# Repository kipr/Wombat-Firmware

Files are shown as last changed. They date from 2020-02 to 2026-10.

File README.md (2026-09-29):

Wombat Firmware
=======
> To view the history of this project, go to https://github.com/kipr/Wallaby-Firmware. This is a direct copy of the Wallaby2-V8 branch of that repository.

# General

This project provides firmware for the STM32F427VIT6 Microcontroller on the Wombat.

It is currently under active development by KIPR.

# Structure

* build
    * This folder contains the output wombat.bin file, which can be flashed onto the microcontroller.
* CMake
    * Toolchain file, to compile the firmare using arm-gcc
* docs
    * Datasheets, Schematics and Bill of Materials for the Wombat Controller
* Firwmare
    * Actual firmware reading the sensors, controlling the motors, ...
* libs
    * STM32 Standard Peripheral Library used to interact with the different periphials of the microcrontroller
* linker
    * STM32F4 linker script

## Run/Build with Docker

> docker compose build

> docker compose run --rm build-wombat-firmware

This builds the firmware and writes wombat.bin to build/Firmware/. Use `run` rather than `up`: `up` reports success even when the build fails.

## Run/Build Directly

(Requires PATH to be setup correctly for gcc/G++)

> sudo build.sh

### Author(s): 
 
Joshua Southerland (2015)

Zachary Sasser (2019)

#### Contributors:
 
Konstantin Lampalzer, [HTL Wiener Neustadt](https://robo4you.at/) (2020) - Added the open-source CMake build and Docker support

Want to Contribute? Start Here!:
https://github.com/kipr/KIPR-Development-Toolkit

Then read [CONTRIBUTING.md](CONTRIBUTING.md) for how we work, including with AI coding agents.

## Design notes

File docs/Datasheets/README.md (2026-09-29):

# Datasheets

Each file is named by the component's reference designator on the Wombat
schematic (`../Schematics/`). Part numbers come from the bill of materials
(`../Wombat_BOM_rev4.xlsx`) and the schematic.

| File | Part | Role |
|---|---|---|
| `U37.pdf` | STMicroelectronics STM32F427VIT6 | Microcontroller this firmware runs on |
| `U5.pdf` | InvenSense MPU-9250 | 9-axis IMU (accelerometer, gyroscope, magnetometer), on SPI3 |
| `U61.pdf`, `U64.pdf` | Toshiba TB6612FNG | Dual H-bridge motor drivers |
| `U38.pdf` | Epson TSX-3225, 24.000 MHz | Main crystal; matches `HSE_VALUE` in `CMakeLists.txt` |
| `U44.pdf` | ECS ECS-.327-12.5-34B, 32.768 kHz | Low-speed crystal |
| `U43.pdf` | Maxim DS1340U-33 | Real-time clock |
| `U2.pdf` | Microchip 24LC02B | 2 Kbit I²C EEPROM |
| `U67.pdf` | Microchip AT24CS01 | 1 Kbit I²C EEPROM with serial number |
| `U56.pdf` | TI TXS0104E | 4-bit bidirectional voltage-level translator |
| `U1.pdf` | TI TFP401 | DVI/HDMI receiver |
| `X1.pdf` | Molex 47151-0001 | HDMI connector |
| `U7.pdf` | TI LM3671MF-3.3 | 3.3 V step-down regulator |
| `U72.pdf`, `U73.pdf` | Diodes Inc. AP65502 | Step-down regulators |
| `U4.pdf` | Fairchild FAN5333B | Voltage regulator |
| `U8.pdf` | Sumida CDRH2D14NP-2R2NC | 2.2 µH inductor |
| `Q1.pdf`, `Q2.pdf` | P-channel MOSFETs | The BOM lists ON Semi NTF6P02T3G; the datasheet files are for Infineon BSP170P |
| `U45 (DNP).pdf` | Maxim MAX98357 | I²S audio amplifier; not populated (DNP) |

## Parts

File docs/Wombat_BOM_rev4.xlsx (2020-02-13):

Item # | Qty | Ref Des | Manufacturer | Mfg Part # | Dist Part # | Distributor | Description | Package | Type | Replacement | Remakrs
66 | 66 | 66 | 66 | 66 | 65 | 66 | 65 | 66 | 66
1 | 1 | J3 | Harwin | M20-7821042 | 855-M20-7821042 | mouser | 1x10 female header | J3 | Thru-hole | 2-1001FBV0T | Chinese Brand
2 | 1 | J1 | Harwin | M20-7831046 | 855-M20-7831046 | mouser | 2x10 female header | 2X10 | Thru-hole | 2-2002FBV0T | Chinese Brand
3 | 1 | J7 | Harwin | M20-7820642 | 855-M20-7820642 | mouser | 1x6 female header | 1X06 | Thru-hole | 2-0601FBV0T | Chinese Brand
4 | 1 | U35 | C&K | 0S102011MA1QN1 | 611-OS102011MA1QN1 | mouser |  | OS-SPDT-MINI-SLIDE_SWITCH | Thru-hole
5 | 4 | R48,R66,R72, R73 | Yageo | RC0603JR-070RL | 603-RC0603JR-070RL | mouser | 0 ohm 0603 | 0603 | smt
6 | 32 | C2, C3,C4,C5,C6,C7,C8, C9, C10, C11,C19,C22, C26, C27, C28, C31, C32, C34, C40, C41, C42, C43, C44, C45, C46, C48, C51, C54, C60, C67, C69, C70 | Taiyo Yuden | TMK107BJ104KA-T | 963-TMK107BJ104KA-T | mouser | 0.1uF 25V | 0603-CAP | smt
7 | 4 | R38, R52, R56,R64 | Yageo | RC0603FR-10100KL | 603-RC0603FR-10100KL | mouser | 100k 1% | 0603-RES | smt
8 | 11 | R1, R2, R5, R8,R11, R32, R45, R50, R54, R58, R65 | Yageo | RC0603FR-0710KL | 603-RC0603FR-0710KL | mouser | 10k 1% | 0603-RES | smt
9 | 2 | R49, R53 | Yageo | RC0603FR-0710K5L | 603-RC0603FR-0710K5L | mouser | 10k5 1% | 0603-RES | smt
10 | 2 | C61, C68 | Yageo | CC0603KRX7R8BB103 | 603-CC603KRX7R8BB103 | mouser | 10nF 25V | 0603-CAP | smt
11 | 1 | C71 | KEMET | C0603C100J5GACTU | 80-C0603C100J5G | mouser | 10pF 50v | 0603 | smt
12 | 1 | C16 | Murata | GRM21BR61E106KA73L | 81-GRM21BR61E106KA3L | mouser | 10uF 20V 20% | 0805-NO | smt
13 | 5 | C1,C29, C30, C49, C50 | Murata | GRM188R61E106MA73J | 81-GRM188R61E106MA3J | mouser | 10uF 20V | 0603-CAP | smt
14 | 2 | R15, R16 | Yageo | RC0805FR-0712RL | 603-RC0805FR-0712RL | mouser | 12 ohm 1% 0805 | 0805-NO | smt
15 | 1 | L1 | Taiyo Yuden | NRS5040T150MMGJV | 963-NRS5040T150MMGJV | mouser | 15uH | INDUCTOR_5X5MM_NR5040_NOTHERMALS | smt
16 | 8 | R9, R10, R12, R13, R28, R30, R31, R57 | Yageo | RC0603FR-071KL | 603-RC0603FR-071KL | mouser | 1K ohm 1% | 0603-RES | smt
17 | 1 | D3 | Fairchild | 1N4148WS | 512-1N4148WS | mouser | 1N4148 | SOD-323 | smt
18 | 2 | C33, C36 | Taiyo Yuden | TMK107B7105KA-T | 587-2984-1-ND | digikey | 1uF | 0603-CAP | smt
19 | 2 | C17, C18 | Yageo | CC0805KKX7R9BB105 | 603-CC805KKX7R9BB105 | mouser | 1uF 50V 10% | 0805-NO | smt
20 | 3 | C37, C38,C12 | Murata | GRM188R61E225KA12D | 81-GRM188R61E225KA2D | mouser | 2.2uF | 0603-CAP | smt
21 | 1 | U8 | Sumida | CDRH2D14NP-2R2NC | 851-CDRH2D14NP-2R2NC | mouser | 2.2uH | 3P2MM-X-3P2MM-INDUCTOR | smt
22 | 6 | C20, C21, C35, C47, C52, C53 | KEMET | C0603C220J5GACTU | 80-C0603C220J5G | mouser | 22pF | 0603 | smt
23 | 6 | C55, C56, C57, C62, C63, C64 | AVX | 1210YD226KAT2A | 581-1210YD226K | mouser | 22uF 16V | 1210@1 | smt | CL32A226KOJNNNE | 22uF(226) ±10% 16V 1210
24 | 1 | R29 | Yageo | RC0603FR-07240RL | 603-RC0603FR-07240RL | mouser | 240R | 0603-RES | smt
25 | 1 | U74 | Littelfuse Inc. | 2920L500/16MR | 576-2920L500/16MR | mouser | 2920L500-16MR 16V 5A Poly Fuse | FUSE-2920 | smt
26 | 1 | J15 | Harwin | M20-7830646 | 855-M20-7830646 | mouser | 2X6 FEMALE | 2X6 | Thru-hole | 2-1202FBV0T | Chinese Brand
27 | 8 | R20, R21, R24, R25, R39, R40, R43, R44 | Yageo | RC0603FR-072K2L | 603-RC0603FR-072K2L | mouser | 2k2 1% | 0603-RES | smt
28 | 1 | C25 | Panasonic | EEE-FTC331XAP | 667-EEE-FTC331XAP | mouser | 330uF 16V Electrolytic Cap | PANASONIC_D | smt
29 | 1 | R37 | Yageo | RC0603FR-073K3L | 603-RC0603FR-073K3L | mouser | 3K3 1% | 0603-RES | smt
30 | 2 | C24, C39 | Murata | GRM188R61E475KE11D | 81-GRM188R61E475KE1D | mouser | 4.7uF | 0603-CAP | smt
31 | 1 | J9 | TE Connectivity | 4-1734839-0 | 571-4-1734839-0 | mouser | Touchscreen Connector 40 Pin | 4-1734839-0 | smt
32 | 8 | R14, R17, R18, R19, R33, R34, R35, R36 | Yageo | RC0603FR-07470RL | 603-RC0603FR-07470RL | mouser | 470R 1% | 0603-RES | smt
33 | 1 | X1 | Molex | 47151-0001 | 538-47151-0001 | mouser | 47151-0001 | HDMI_MOLEX_47151-0001_DIMLAYER | smt, thru-hole posts
34 | 1 | R7 | Yageo | RC0603FR-0747KL | 603-RC0603FR-0747KL | mouser | 47k 1% | 0603 | smt
35 | 2 | C58, C65 | Murata | GRM32EC81C476KE15L | 81-GRM32EC81C476KE5L | mouser | 47uF 10%ToL | 1210@1 | smt
36 | 1 | R55 | Yageo | RC0603FR-0752K3L | 603-RC0603FR-0752K3L | mouser | 52k3 1% | 0603-RES | smt
37 | 2 | L2,L4 | Vishay | IHLP3232CZER6R8M01 | 70-IHLP3232CZER6R8M0 | mouser | 6.5uH | INDUCT-3232-1050 | smt
38 | 1 | R51 | Yageo | RC0603FR-0764K9L | 603-RC0603FR-0764K9L | mouser | 64k9 1% | 0603-RES | smt
39 | 8 | R22, R23, R26, R27, R41, R42, R46, R47 | Yageo | RC0603FR-076K8L | 603-RC0603FR-076K8L | mouser | 6k8 1% | 0603-RES | smt
40 | 2 | C59, C66 | Yageo | CC0603JRX7R9BB682 | 603-CC603JRX7R9BB682 | mouser | 6p8nF | 0603-CAP | smt
41 | 1 | U5 | InvenSense | MPU-9250 | 1428-1019-1-ND | digikey | 9DoF IMU | QFN24-3X3 | smt
42 | 1 | U$8 | Texas Instruments | TSC2007IPWR | 595-TSC2007IPWR | mouser | TSC2007 | TSSOP16 | smt
43 | 2 | U72, U73 | Diodes Incorporated | AP65502SP-13 | 621-AP65502SP-13 | mouser | DC/DC Buck | SOT-23-Thin-6 | smt
44 | 4 | U62, U63, U65, U66 | Kingbright | APB3025ESGC-F01 | 604-APB3025ESGC-F01 | mouser | APB3025ESGC-F01 | DUAL_SMT_LED | smt
45 | 1 | U67 | Microchip | AT24CS01-STUM-T | 556-AT24CS01-STUM-T | mouser | AT24CS01-STUM-T | SOT-23-5 | smt
46 | 2 | Q1, Q2 | ON Semiconductor | NTF6P02T3G | 863-NTF6P02T3G | mouser | P-CH 20V FET | SOT223 | smt
47 | 1 | U42 | Keystone | 2998TR | 534-2998TR | mouser | COINCELL_6P8MM | COIN_CELL_HOLDER_6P8MM | smt
48 | 4 | U30, U41, U76, U77 | TE Connectivity | 5-103414-1 | 571-5-103414-1 | mouser | CONN-HEADER-5-103414-1 | HEADER-5-103414-1 | Thru-hole
49 | 1 | J2 | Adafruit | 1992 |  | adafruit | 2x20 tall female Pi connector | 2X20 | Thru-hole | Still sourcing for lower price
50 | 1 | U44 | ECS | ECS-.327-12.5-34B-TR | 520-327-12.5-34B | mouser | CRYSTAL-ECS-ECX34B 32.768KHz | CRYSTAL-ECX34B-3P2MM_1P5MM | smt
51 | 1 | U43 | Maxim Integrated | DS1340U-33+ | 700-DS1340U-33 | mouser | DS1340U | USOP-8 | smt | DS1340U-33+T&R | Detailed part number is DS1340U-33+T&R
52 | 1 | U4 | Fairchild | FAN5333BSX | 512-FAN5333BSX | mouser | FAN5333BSX | SOT23-5 | smt
53 | 2 | J8, J10 | Harwin | M20-7830342 | 855-M20-7830342 | mouser | FEMALE 2x3 | 2X3 | Thru-hole | 2-0602FBV0T | Chinese Brand
54 | 4 | U68, U69, U70, U71 | Littelfuse Inc. | 0603L175SLYR | 576-0603L175SLYR | mouser | FUSE-RESET-0603L100SLYR | 0603 | smt
55 | 4 | FB1, FB2, FB3, FB4 | Murata | BLM21AG601SN1D | 81-BLM21A601F | mouser | Ferrite | _0805MP | smt
56 | 1 | U7 | Texas Instruments | LM3671MF-3.3/NOPB | 926-LM3671MF-3.3NOPB | mouser | LM3671 | SOT-23-5 | smt
57 | 1 | D1 | Fairchild | MBR0540 | 512-MBR0540 | mouser | MBR0540 | SOD-123 | smt
58 | 1 | D2 | OM Semiconductor | 1SMB5934BT3G | 863-1SMB5934BT3G | mouser | 24V 3W Zener | SMADIODE | smt
59 | 1 | U75 | TE Connectivity | 1571527-2 | 506-1571527-2 | mouser | PUSHBUTTON-1571527-2 | BUTTON-1571527-2 | smt
60 | 1 | U37 | STMicroelectronics | STM32F427VIT6 | 511-STM32F427VIT6 | mouser | STM32F427VIT6 | LQFP-100 | smt
61 | 2 | U61, U64 | Toshiba | TB6612FNG,C,8,EL | 757-TB6612FNGC8EL | mouser | TB6612FNG | SSOP24 | smt
62 | 1 | U1 | Texas Instruments | TFP401AIPZPRQ1 | 595-TFP401AIPZPRQ1 | mouser | TFP401 | S-PQFP-G100 | smt
63 | 1 | U38 | Epson Timing | TSX-3225 24.0000MF20G-AC3 | 732-TX325-24F20G-AC3 | mouser | TSX-3325 24.000MHz Crystal | TSX-3225 | smt
64 | 1 | U56 | Texas Instruments | TXS0104EPWR | 595-TXS0104EPWR | mouser | TXS0104 | TSSOP14 | smt
65 | 1 | D4 | Lite-On | LTST-C190KRKT | 859-LTST-C190KRKT | mouser | Red 0603 led | LED-0603 | smt
66 | 1 | D5 | Lite-On | LTST-C190KSKT | 859-LTST-C190KSKT | mouser | Yellow 0603 led | LED-0603 | smt

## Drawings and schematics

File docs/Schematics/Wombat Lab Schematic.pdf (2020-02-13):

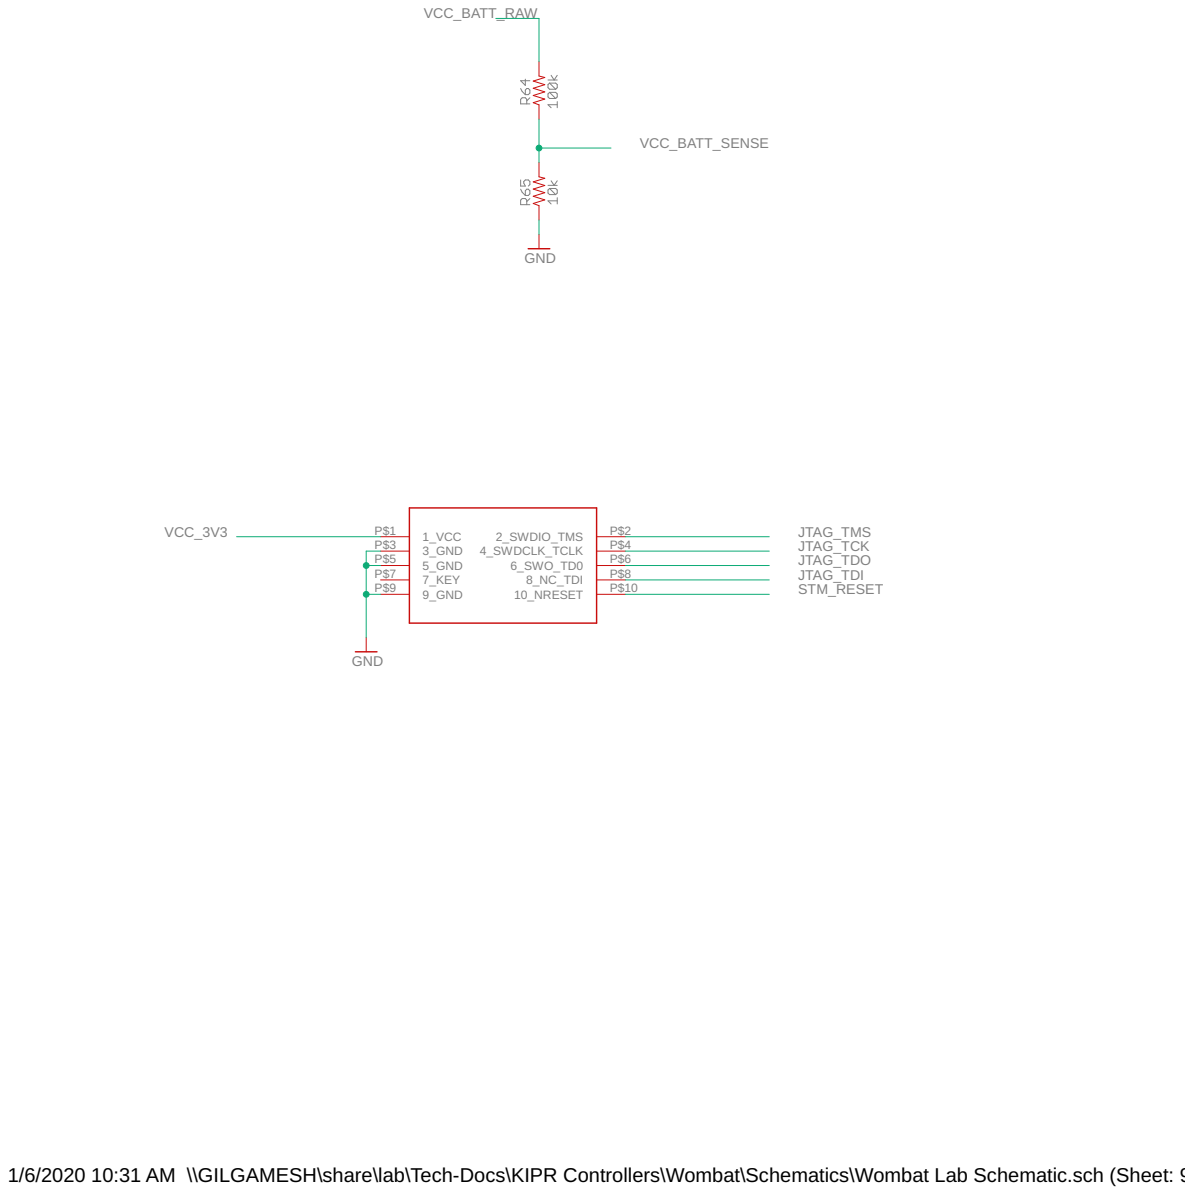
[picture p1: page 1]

1/6/2020 10:31 AM \\GILGAMESH\share\lab\Tech-Docs\KIPR Controllers\Wombat\Schematics\Wombat Lab Schematic.sch (Sheet: 9/17)

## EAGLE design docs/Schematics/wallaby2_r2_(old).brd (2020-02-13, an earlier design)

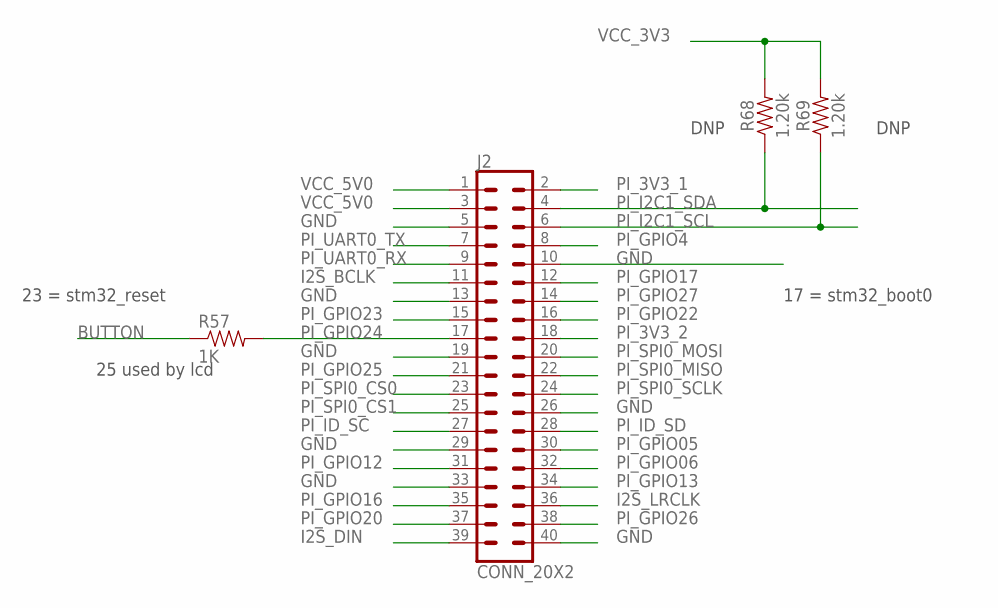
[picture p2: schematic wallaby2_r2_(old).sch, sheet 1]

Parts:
J2: CONN_20X2; 2X20
R57: 1K; 0603-RES
R68, R69: 1.20k; 0603

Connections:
BUTTON: R57.1; also elsewhere on the board
GND: J2.5, J2.10, J2.13, J2.19, J2.26, J2.29, J2.33, J2.40; also elsewhere on the board
I2S_BCLK: J2.11; also elsewhere on the board
I2S_DIN: J2.39; also elsewhere on the board
I2S_LRCLK: J2.36; also elsewhere on the board
PI_3V3_1: J2.2
PI_3V3_2: J2.18
PI_GPIO4: J2.8
PI_GPIO05: J2.30
PI_GPIO06: J2.32
PI_GPIO12: J2.31
PI_GPIO13: J2.34
PI_GPIO16: J2.35
PI_GPIO17: J2.12; also elsewhere on the board
PI_GPIO20: J2.37
PI_GPIO22: J2.16
PI_GPIO23: J2.15; also elsewhere on the board
PI_GPIO24: J2.17, R57.2
PI_GPIO25: J2.21; also elsewhere on the board
PI_GPIO26: J2.38
PI_GPIO27: J2.14
PI_I2C1_SCL: J2.6, R69.1; also elsewhere on the board
PI_I2C1_SDA: J2.4, R68.1; also elsewhere on the board
PI_ID_SC: J2.27
PI_ID_SD: J2.28
PI_SPI0_CS0: J2.23; also elsewhere on the board
PI_SPI0_CS1: J2.25
PI_SPI0_MISO: J2.22; also elsewhere on the board
PI_SPI0_MOSI: J2.20; also elsewhere on the board
PI_SPI0_SCLK: J2.24; also elsewhere on the board
PI_UART0_RX: J2.9; also elsewhere on the board
PI_UART0_TX: J2.7; also elsewhere on the board
VCC_3V3: R68.2, R69.2; also elsewhere on the board
VCC_5V0: J2.1, J2.3; also elsewhere on the board

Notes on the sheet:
25 used by lcd
23 = stm32_reset
17 = stm32_boot0
DNP

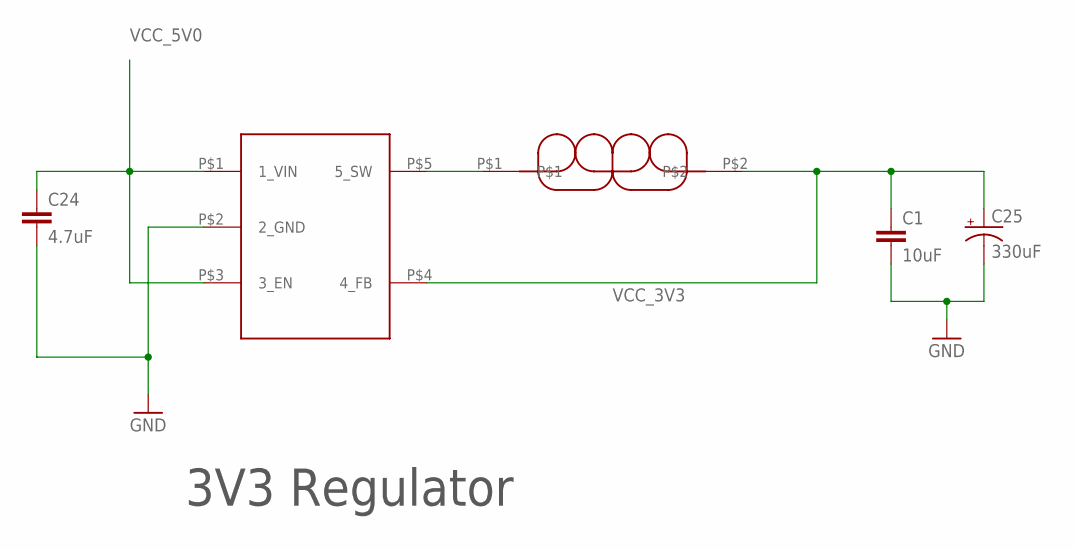
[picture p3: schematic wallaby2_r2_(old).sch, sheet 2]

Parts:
C1: 10uF; 0603-CAP
C24: 4.7uF; 0603-CAP
C25: 330uF; PANASONIC_D
U7: LM3671; SOT-23-5
U8: 2.2uH; 3P2MM-X-3P2MM-INDUCTOR

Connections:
GND: C1.2, C24.2, C25.-, U7.P$2 (2_GND); also elsewhere on the board
unnamed: U7.P$5 (5_SW), U8.P$1
VCC_3V3: C1.1, C25.+, U7.P$4 (4_FB), U8.P$2; also elsewhere on the board
VCC_5V0: C24.1, U7.P$1 (1_VIN), U7.P$3 (3_EN); also elsewhere on the board

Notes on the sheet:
3V3 Regulator

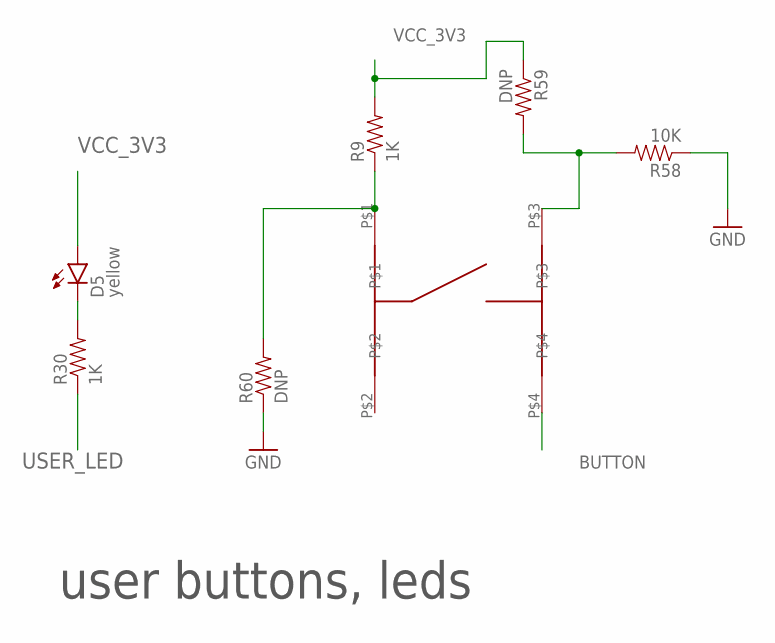
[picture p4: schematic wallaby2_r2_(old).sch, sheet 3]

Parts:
D5: yellow; LED-0603
R9, R30: 1K; 0603-RES
R58: 10K; 0603-RES
R59, R60: DNP; 0603-RES
U75: PUSHBUTTON-1571527-2; BUTTON-1571527-2

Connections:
BUTTON: U75.P$4; also elsewhere on the board
GND: R58.1, R60.1; also elsewhere on the board
unnamed: D5.C, R30.2
unnamed: R9.1, R60.2, U75.P$1
unnamed: R58.2, R59.2, U75.P$3
USER_LED: R30.1; also elsewhere on the board
VCC_3V3: D5.A, R9.2, R59.1; also elsewhere on the board

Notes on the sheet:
user buttons, leds

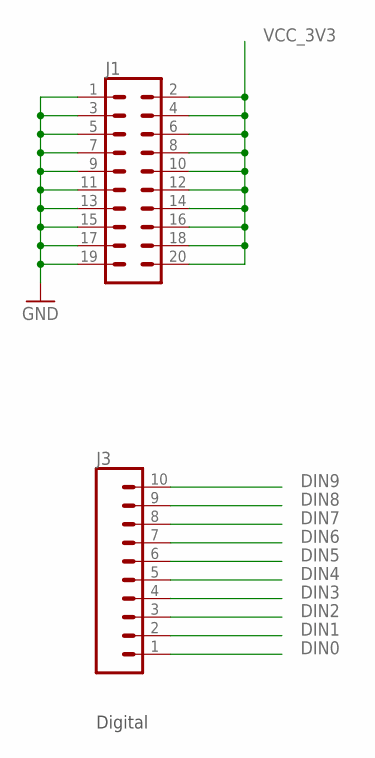
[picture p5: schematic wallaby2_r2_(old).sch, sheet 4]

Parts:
J1: CONN_10X2; 2X10
J3: CONN_10"; 1X10

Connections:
DIN0: J3.1; also elsewhere on the board
DIN1: J3.2; also elsewhere on the board
DIN2: J3.3; also elsewhere on the board
DIN3: J3.4; also elsewhere on the board
DIN4: J3.5; also elsewhere on the board
DIN5: J3.6; also elsewhere on the board
DIN6: J3.7; also elsewhere on the board
DIN7: J3.8; also elsewhere on the board
DIN8: J3.9; also elsewhere on the board
DIN9: J3.10; also elsewhere on the board
GND: J1.1, J1.3, J1.5, J1.7, J1.9, J1.11, J1.13, J1.15, J1.17, J1.19; also elsewhere on the board
VCC_3V3: J1.2, J1.4, J1.6, J1.8, J1.10, J1.12, J1.14, J1.16, J1.18, J1.20; also elsewhere on the board

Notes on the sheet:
Digital

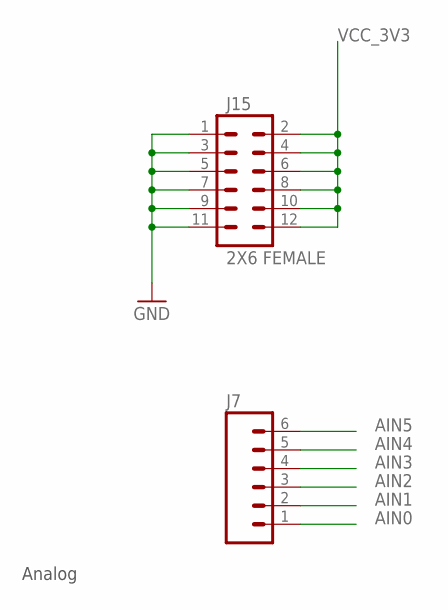
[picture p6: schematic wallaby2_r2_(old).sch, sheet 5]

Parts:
J7: M06SILK_FEMALE_PTH; 1X06
J15: 2X6 FEMALE; 2X6

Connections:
AIN0: J7.1; also elsewhere on the board
AIN1: J7.2; also elsewhere on the board
AIN2: J7.3; also elsewhere on the board
AIN3: J7.4; also elsewhere on the board
AIN4: J7.5; also elsewhere on the board
AIN5: J7.6; also elsewhere on the board
GND: J15.1, J15.3, J15.5, J15.7, J15.9, J15.11; also elsewhere on the board
VCC_3V3: J15.2, J15.4, J15.6, J15.8, J15.10, J15.12; also elsewhere on the board

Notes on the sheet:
Analog

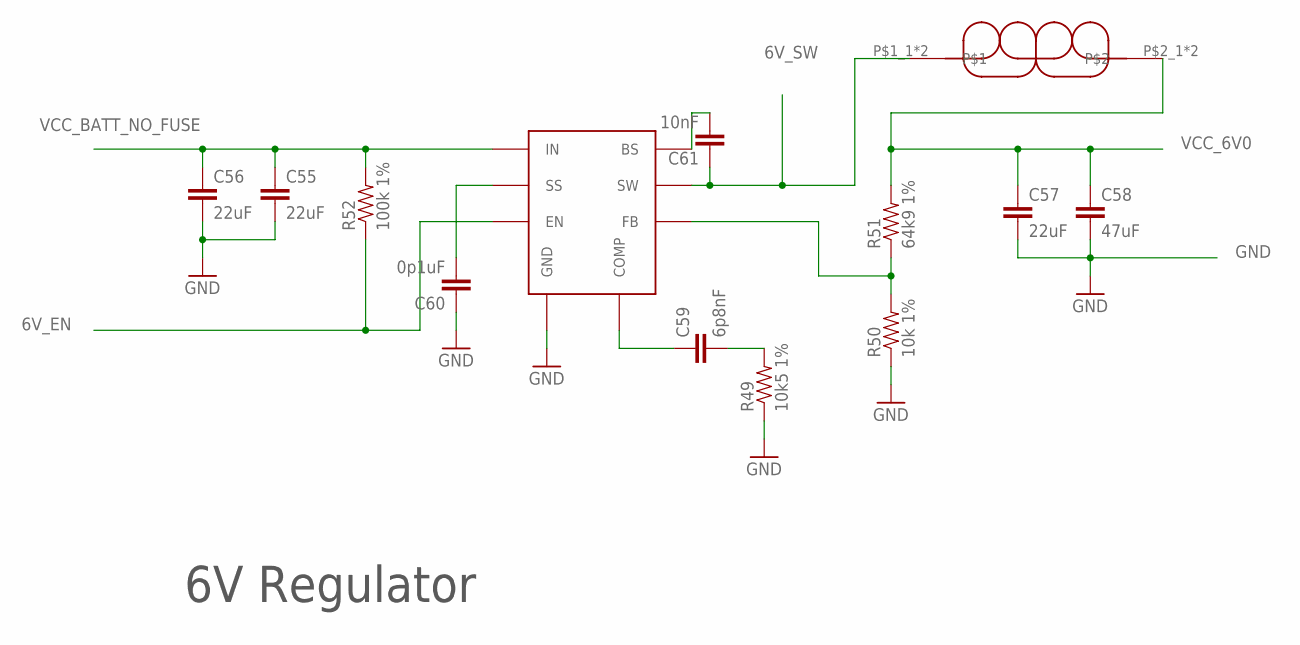
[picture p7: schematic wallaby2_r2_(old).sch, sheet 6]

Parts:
C55, C56, C57: 22uF; 1210@1
C58: 47uF; 1210@1
C59: 6p8nF; 0603-CAP
C60: 0p1uF; 0603-CAP
C61: 10nF; 0603-CAP
L2: 6.5uH; INDUCT-3232-1050
R49: 10k5 1%; 0603-RES
R50: 10k 1%; 0603-RES
R51: 64k9 1%; 0603-RES
R52: 100k 1%; 0603-RES
U72: AP65502; SO-8EP

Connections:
6V_EN: R52.1, U72.7 (EN); also elsewhere on the board
6V_SW: C61.1, L2.P$1_1, L2.P$1_2, U72.3 (SW)
GND: C55.2, C56.2, C57.2, C58.2, C60.1, R49.1, R50.1, U72.4 (GND), U72.GND, U72.V$1 (GND), U72.V$2 (GND), U72.V$3 (GND), U72.V$4 (GND), U72.V$5 (GND), U72.V$6 (GND), U72.V$7 (GND), U72.V$8 (GND), U72.V$9 (GND), U72.V$10 (GND), U72.V$11 (GND), U72.V$12 (GND), U72.V$13 (GND), U72.V$14 (GND), U72.V$15 (GND); also elsewhere on the board
unnamed: C61.2, U72.1 (BS)
unnamed: C59.1, U72.6 (COMP)
unnamed: C59.2, R49.2
unnamed: C60.2, U72.8 (SS)
unnamed: R50.2, R51.1, U72.5 (FB)
VCC_6V0: C57.1, C58.1, L2.P$2_1, L2.P$2_2, R51.2; also elsewhere on the board
VCC_BATT_NO_FUSE: C55.1, C56.1, R52.2, U72.2 (IN); also elsewhere on the board

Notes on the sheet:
6V Regulator

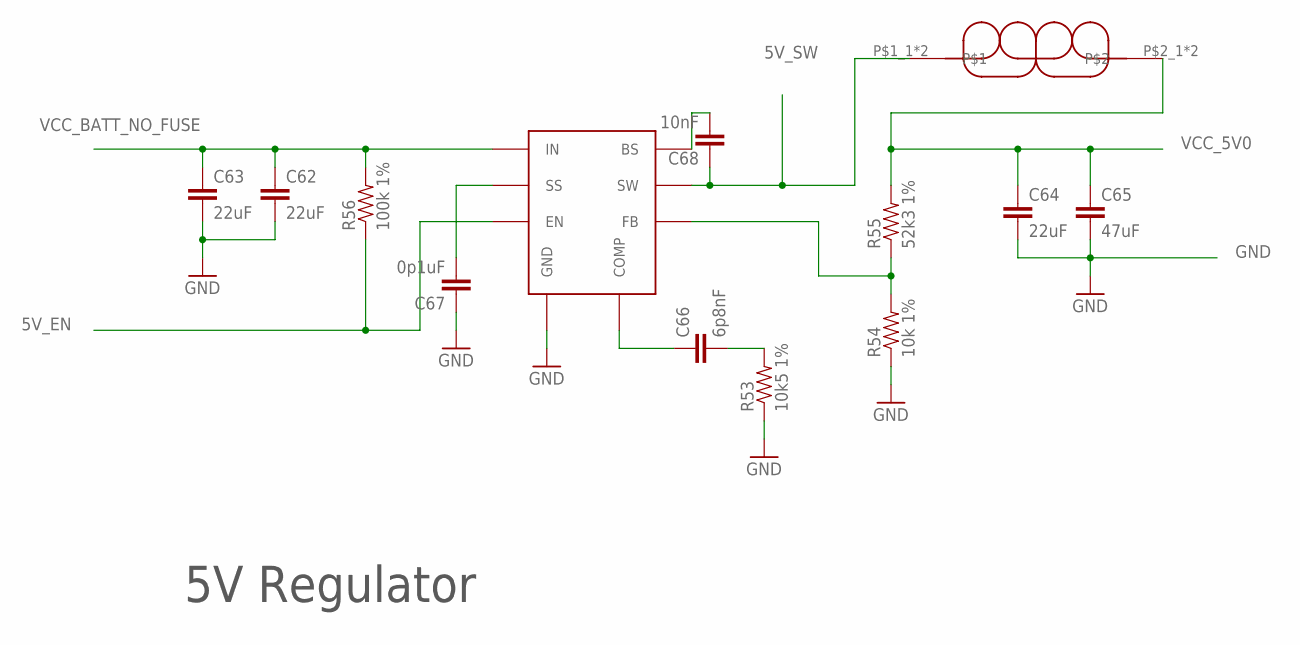
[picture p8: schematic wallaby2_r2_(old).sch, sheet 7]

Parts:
C62, C63, C64: 22uF; 1210@1
C65: 47uF; 1210@1
C66: 6p8nF; 0603-CAP
C67: 0p1uF; 0603-CAP
C68: 10nF; 0603-CAP
L4: 6.5uH; INDUCT-3232-1050
R53: 10k5 1%; 0603-RES
R54: 10k 1%; 0603-RES
R55: 52k3 1%; 0603-RES
R56: 100k 1%; 0603-RES
U73: AP65502; SO-8EP

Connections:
5V_EN: R56.1, U73.7 (EN)
5V_SW: C68.1, L4.P$1_1, L4.P$1_2, U73.3 (SW)
GND: C62.2, C63.2, C64.2, C65.2, C67.1, R53.1, R54.1, U73.4 (GND), U73.GND, U73.V$1 (GND), U73.V$2 (GND), U73.V$3 (GND), U73.V$4 (GND), U73.V$5 (GND), U73.V$6 (GND), U73.V$7 (GND), U73.V$8 (GND), U73.V$9 (GND), U73.V$10 (GND), U73.V$11 (GND), U73.V$12 (GND), U73.V$13 (GND), U73.V$14 (GND), U73.V$15 (GND); also elsewhere on the board
unnamed: C68.2, U73.1 (BS)
unnamed: C66.1, U73.6 (COMP)
unnamed: C66.2, R53.2
unnamed: C67.2, U73.8 (SS)
unnamed: R54.2, R55.1, U73.5 (FB)
VCC_5V0: C64.1, C65.1, L4.P$2_1, L4.P$2_2, R55.2; also elsewhere on the board
VCC_BATT_NO_FUSE: C62.1, C63.1, R56.2, U73.2 (IN); also elsewhere on the board

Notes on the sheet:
5V Regulator

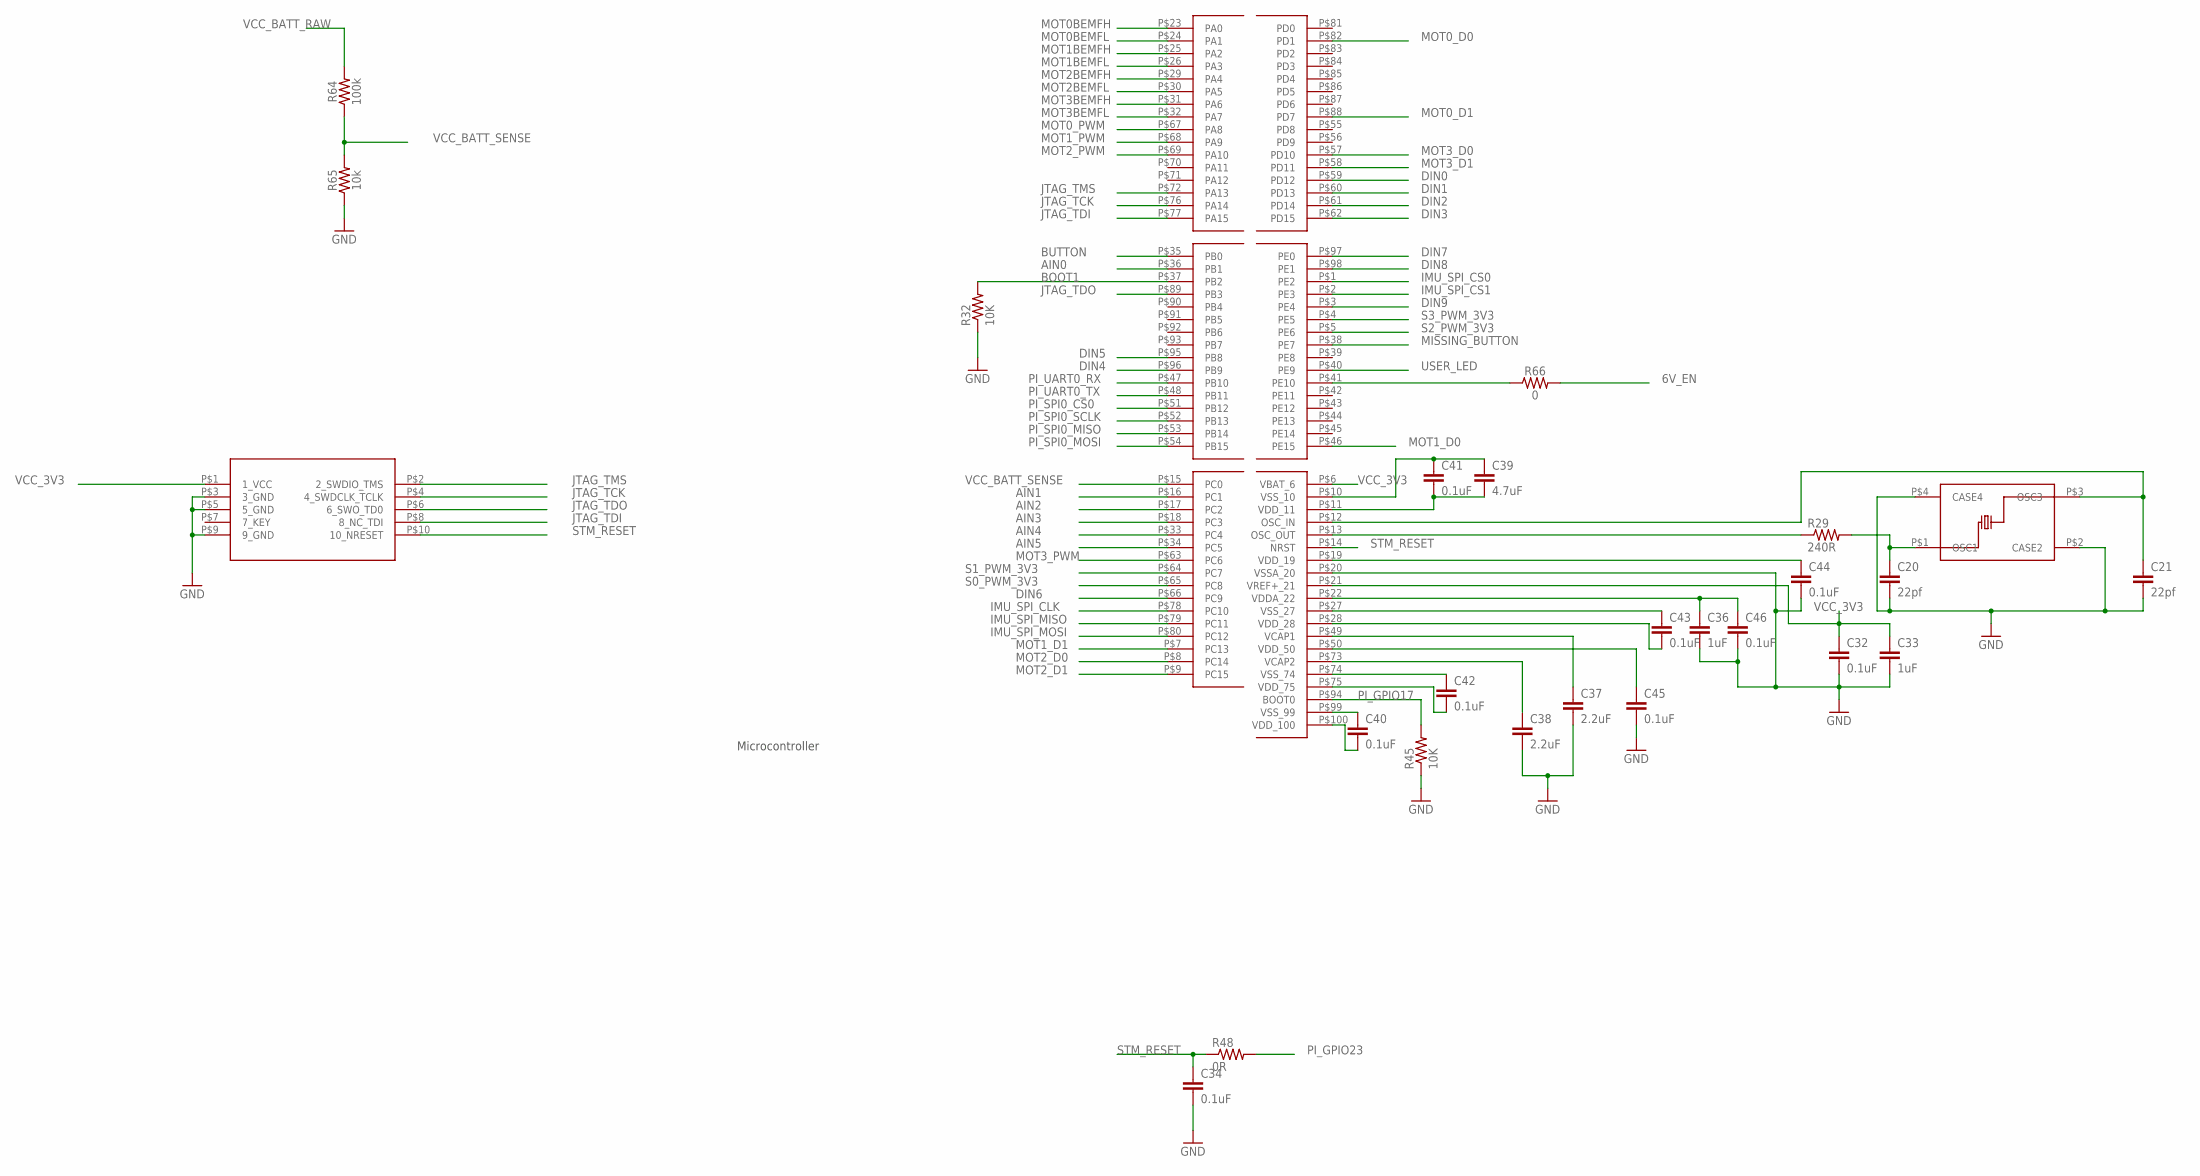
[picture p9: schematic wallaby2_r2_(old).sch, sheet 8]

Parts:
C20, C21: 22pf; 0603-CAP
C32, C34, C40, C41, C42, C43, C44, C45, C46: 0.1uF; 0603-CAP
C33, C36: 1uF; 0603-CAP
C37, C38: 2.2uF; 0603-CAP
C39: 4.7uF; 0603-CAP
R29: 240R; 0603-RES
R32, R45: 10K; 0603-RES
R48: 0R; 0603-RES
R64: 100k; 0603
R65: 10k; 0603
R66: 0; 0603
U37: STM32F427VIT6; LQFP-100
U38: TSX-3325; TSX-3225
U39: CORTEX_JTAG; CORTEX-JTAG-HDR

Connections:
6V_EN: R66.2; also elsewhere on the board
AIN0: U37.P$36 (PB1); also elsewhere on the board
AIN1: U37.P$16 (PC1); also elsewhere on the board
AIN2: U37.P$17 (PC2); also elsewhere on the board
AIN3: U37.P$18 (PC3); also elsewhere on the board
AIN4: U37.P$33 (PC4); also elsewhere on the board
AIN5: U37.P$34 (PC5); also elsewhere on the board
BOOT1: R32.2, U37.P$37 (PB2)
BUTTON: U37.P$35 (PB0); also elsewhere on the board
DIN0: U37.P$59 (PD12); also elsewhere on the board
DIN1: U37.P$60 (PD13); also elsewhere on the board
DIN2: U37.P$61 (PD14); also elsewhere on the board
DIN3: U37.P$62 (PD15); also elsewhere on the board
DIN4: U37.P$96 (PB9); also elsewhere on the board
DIN5: U37.P$95 (PB8); also elsewhere on the board
DIN6: U37.P$66 (PC9); also elsewhere on the board
DIN7: U37.P$97 (PE0); also elsewhere on the board
DIN8: U37.P$98 (PE1); also elsewhere on the board
DIN9: U37.P$3 (PE4); also elsewhere on the board
GND: C20.2, C21.2, C32.2, C33.2, C34.2, C36.2, C37.2, C38.2, C39.1, C40.1, C41.1, C42.1, C43.1, C44.2, C45.2, C46.2, R32.1, R45.1, R65.1, U37.P$10 (VSS_10), U37.P$20 (VSSA_20), U37.P$27 (VSS_27), U37.P$74 (VSS_74), U37.P$99 (VSS_99), U38.P$2 (CASE2), U38.P$4 (CASE4), U39.P$3 (3_GND), U39.P$5 (5_GND), U39.P$9 (9_GND); also elsewhere on the board
IMU_SPI_CLK: U37.P$78 (PC10); also elsewhere on the board
IMU_SPI_CS0: U37.P$1 (PE2); also elsewhere on the board
IMU_SPI_CS1: U37.P$2 (PE3)
IMU_SPI_MISO: U37.P$79 (PC11); also elsewhere on the board
IMU_SPI_MOSI: U37.P$80 (PC12); also elsewhere on the board
JTAG_TCK: U37.P$76 (PA14), U39.P$4 (4_SWDCLK_TCLK)
JTAG_TDI: U37.P$77 (PA15), U39.P$8 (8_NC_TDI)
JTAG_TDO: U37.P$89 (PB3), U39.P$6 (6_SWO_TD0)
JTAG_TMS: U37.P$72 (PA13), U39.P$2 (2_SWDIO_TMS)
MISSING_BUTTON: U37.P$38 (PE7)
MOT0BEMFH: U37.P$23 (PA0); also elsewhere on the board
MOT0BEMFL: U37.P$24 (PA1); also elsewhere on the board
MOT0_D0: U37.P$82 (PD1); also elsewhere on the board
MOT0_D1: U37.P$88 (PD7); also elsewhere on the board
MOT0_PWM: U37.P$67 (PA8); also elsewhere on the board
MOT1BEMFH: U37.P$25 (PA2); also elsewhere on the board
MOT1BEMFL: U37.P$26 (PA3); also elsewhere on the board
MOT1_D0: U37.P$46 (PE15); also elsewhere on the board
MOT1_D1: U37.P$7 (PC13); also elsewhere on the board
MOT1_PWM: U37.P$68 (PA9); also elsewhere on the board
MOT2BEMFH: U37.P$29 (PA4); also elsewhere on the board
MOT2BEMFL: U37.P$30 (PA5); also elsewhere on the board
MOT2_D0: U37.P$8 (PC14); also elsewhere on the board
MOT2_D1: U37.P$9 (PC15); also elsewhere on the board
MOT2_PWM: U37.P$69 (PA10); also elsewhere on the board
MOT3BEMFH: U37.P$31 (PA6); also elsewhere on the board
MOT3BEMFL: U37.P$32 (PA7); also elsewhere on the board
MOT3_D0: U37.P$57 (PD10); also elsewhere on the board
MOT3_D1: U37.P$58 (PD11); also elsewhere on the board
MOT3_PWM: U37.P$63 (PC6); also elsewhere on the board
unnamed: C20.1, R29.2, U38.P$1 (OSC1)
unnamed: R66.1, U37.P$41 (PE10)
OSC_IN: C21.1, U37.P$12 (OSC_IN), U38.P$3 (OSC3)
OSC_OUT: R29.1, U37.P$13 (OSC_OUT)
PI_GPIO17: R45.2, U37.P$94 (BOOT0); also elsewhere on the board
PI_GPIO23: R48.2; also elsewhere on the board
PI_SPI0_CS0: U37.P$51 (PB12); also elsewhere on the board
PI_SPI0_MISO: U37.P$53 (PB14); also elsewhere on the board
PI_SPI0_MOSI: U37.P$54 (PB15); also elsewhere on the board
PI_SPI0_SCLK: U37.P$52 (PB13); also elsewhere on the board
PI_UART0_RX: U37.P$47 (PB10); also elsewhere on the board
PI_UART0_TX: U37.P$48 (PB11); also elsewhere on the board
S0_PWM_3V3: U37.P$65 (PC8); also elsewhere on the board
S1_PWM_3V3: U37.P$64 (PC7); also elsewhere on the board
S2_PWM_3V3: U37.P$5 (PE6); also elsewhere on the board
S3_PWM_3V3: U37.P$4 (PE5); also elsewhere on the board
STM_RESET: C34.1, R48.1, U37.P$14 (NRST), U39.P$10 (10_NRESET)
USER_LED: U37.P$40 (PE9); also elsewhere on the board
VCAP1: C37.1, U37.P$49 (VCAP1)
VCAP2: C38.1, U37.P$73 (VCAP2)
VCC_3V3: C32.1, C33.1, C36.1, C39.2, C40.2, C41.2, C42.2, C43.2, C44.1, C45.1, C46.1, U37.P$6 (VBAT_6), U37.P$11 (VDD_11), U37.P$19 (VDD_19), U37.P$21 (VREF+_21), U37.P$22 (VDDA_22), U37.P$28 (VDD_28), U37.P$50 (VDD_50), U37.P$75 (VDD_75), U37.P$100 (VDD_100), U39.P$1 (1_VCC); also elsewhere on the board
VCC_BATT_RAW: R64.2; also elsewhere on the board
VCC_BATT_SENSE: R64.1, R65.2, U37.P$15 (PC0)

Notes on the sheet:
Microcontroller

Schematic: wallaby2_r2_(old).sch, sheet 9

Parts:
C22: 0.1uF; 0603-CAP
R11: 10K; 0603-RES
U42: COINCELL_6P8MM; COIN_CELL_HOLDER_6P8MM
U43: DS1340U; USOP-8
U44: CRYSTAL-ECS-ECX34B; CRYSTAL-ECX34B-3P2MM_1P5MM

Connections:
GND: C22.1, U42.P_MIN, U43.P$4 (4_GND); also elsewhere on the board
unnamed: U42.P_PLUS_1, U42.P_PLUS_2, U43.P$3 (3_VBAT)
unnamed: U43.P$2 (2_X2), U44.P$2
unnamed: U43.P$1 (1_X1), U44.P$1
unnamed: R11.1, U43.P$7 (7_OUT)
PI_I2C1_SCL: U43.P$6 (6_SCL); also elsewhere on the board
PI_I2C1_SDA: U43.P$5 (5_SDA); also elsewhere on the board
VCC_3V3: C22.2, R11.2, U43.P$8 (8_VCC); also elsewhere on the board

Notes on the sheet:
RTC and Battery Backup

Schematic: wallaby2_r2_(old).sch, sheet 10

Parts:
C26, C27: 0.1uF; 0603-CAP
U30, U41, U76, U77: CONN-HEADER-5-103414-1; HEADER-5-103414-1
U56: TXS0104; TSSOP14
U68, U69, U70, U71: FUSE-RESET-0603L100SLYR; 0603

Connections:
GND: C26.2, C27.2, U30.P$3, U41.P$3, U56.P$7 (7_GND), U76.P$3, U77.P$3; also elsewhere on the board
unnamed: U71.P$2, U77.P$2
unnamed: U70.P$2, U76.P$2
unnamed: U30.P$2, U68.P$2
unnamed: U41.P$2, U69.P$2
S0_PWM_3V3: U56.P$5 (5_A4); also elsewhere on the board
S0_PWM_5V0: U30.P$1, U56.P$10 (10_B4)
S1_PWM_3V3: U56.P$4 (4_A3); also elsewhere on the board
S1_PWM_5V0: U41.P$1, U56.P$11 (11_B3)
S2_PWM_3V3: U56.P$3 (3_A2); also elsewhere on the board
S2_PWM_5V0: U56.P$12 (12_B2), U76.P$1
S3_PWM_3V3: U56.P$2 (2_A1); also elsewhere on the board
S3_PWM_5V0: U56.P$13 (13_B1), U77.P$1
VCC_3V3: C27.1, U56.P$1 (1_VCCA), U56.P$8 (8_OE); also elsewhere on the board
VCC_5V0: C26.1, U56.P$14 (14_VCCB); also elsewhere on the board
VCC_6V0: U68.P$1, U69.P$1, U70.P$1, U71.P$1; also elsewhere on the board

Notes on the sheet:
Servos

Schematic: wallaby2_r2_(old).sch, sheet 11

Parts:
C28, C31, C48, C51: 0.1uF 20V; 0603-CAP
C29, C30, C49, C50: 10uF 20V; 0603-CAP
C35, C47, C52, C53: 22pf; 0603-CAP
J8, J10: FEMALE 2x3; 2X3
R12, R13, R28, R31: 1K; 0603-RES
R14, R17, R18, R19, R33, R34, R35, R36: 470R; 0603-RES
R20, R21, R24, R25, R39, R40, R43, R44: 2k2; 0603-RES
R22, R23, R26, R27, R41, R42, R46, R47: 6k8; 0603-RES
U61, U64: TB6612FNG; SSOP24
U62, U63, U65, U66: APB3025ESGC-F01; DUAL_SMT_LED

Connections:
GND: C28.2, C29.2, C30.2, C31.2, C48.2, C49.2, C50.2, C51.2, R17.1, R19.1, R34.1, R36.1, U61.P$3 (PGND1_3), U61.P$4 (PGND1_4), U61.P$9 (PGND2_9), U61.P$10 (PGND2_10), U61.P$18 (GND_18), U64.P$3 (PGND1_3), U64.P$4 (PGND1_4), U64.P$9 (PGND2_9), U64.P$10 (PGND2_10), U64.P$18 (GND_18); also elsewhere on the board
MOT0A: J8.2, J8.4, R26.2, U61.P$1 (AO1_1), U61.P$2 (AO1_2), U63.P$2, U63.P$3
MOT0B: J8.6, R12.1, R27.2, U61.P$5 (AO2_5), U61.P$6 (AO2_6)
MOT0BEMFH: C47.2, R24.2, R26.1; also elsewhere on the board
MOT0BEMFL: C47.1, R25.2, R27.1; also elsewhere on the board
MOT0_D0: U61.P$21 (AIN1_21); also elsewhere on the board
MOT0_D1: U61.P$22 (AIN2_22); also elsewhere on the board
MOT0_PWM: U61.P$23 (PWMA_23); also elsewhere on the board
MOT1A: J8.1, J8.3, R22.2, U61.P$11 (BO1_11), U61.P$12 (BO1_12), U62.P$2, U62.P$3
MOT1B: J8.5, R13.2, R23.2, U61.P$7 (BO2_7), U61.P$8 (BO2_8)
MOT1BEMFH: C35.2, R20.2, R22.1; also elsewhere on the board
MOT1BEMFL: C35.1, R21.2, R23.1; also elsewhere on the board
MOT1_D0: U61.P$17 (BIN1_17); also elsewhere on the board
MOT1_D1: U61.P$16 (BIN2_16); also elsewhere on the board
MOT1_PWM: U61.P$15 (PWMB_15); also elsewhere on the board
MOT2A: J10.2, J10.4, R46.2, U64.P$1 (AO1_1), U64.P$2 (AO1_2), U66.P$2, U66.P$3
MOT2B: J10.6, R28.1, R47.2, U64.P$5 (AO2_5), U64.P$6 (AO2_6)
MOT2BEMFH: C53.2, R43.2, R46.1; also elsewhere on the board
MOT2BEMFL: C53.1, R44.2, R47.1; also elsewhere on the board
MOT2_D0: U64.P$21 (AIN1_21); also elsewhere on the board
MOT2_D1: U64.P$22 (AIN2_22); also elsewhere on the board
MOT2_PWM: U64.P$23 (PWMA_23); also elsewhere on the board
MOT3A: J10.1, J10.3, R41.2, U64.P$11 (BO1_11), U64.P$12 (BO1_12), U65.P$2, U65.P$3
MOT3B: J10.5, R31.2, R42.2, U64.P$7 (BO2_7), U64.P$8 (BO2_8)
MOT3BEMFH: C52.2, R39.2, R41.1; also elsewhere on the board
MOT3BEMFL: C52.1, R40.2, R42.1; also elsewhere on the board
MOT3_D0: U64.P$17 (BIN1_17); also elsewhere on the board
MOT3_D1: U64.P$16 (BIN2_16); also elsewhere on the board
MOT3_PWM: U64.P$15 (PWMB_15); also elsewhere on the board
N22: R13.1, U62.P$1, U62.P$4
N43: R31.1, U65.P$1, U65.P$4
N44: R28.2, U66.P$1, U66.P$4
unnamed: R12.2, U63.P$1, U63.P$4
unnamed: R18.1, R19.2, R20.1, R21.1
unnamed: R14.1, R17.2, R24.1, R25.1
unnamed: R35.1, R36.2, R39.1, R40.1
unnamed: R33.1, R34.2, R43.1, R44.1
VCC_3V3: C30.1, C31.1, C50.1, C51.1, R14.2, R18.2, R33.2, R35.2, U61.P$19 (STBY_19), U61.P$20 (VCC_20), U64.P$19 (STBY_19), U64.P$20 (VCC_20); also elsewhere on the board
VCC_BATT_FUSE: C28.1, C29.1, C48.1, C49.1, U61.P$13 (VM2_13), U61.P$14 (VM3_14), U61.P$24 (VM1_24), U64.P$13 (VM2_13), U64.P$14 (VM3_14), U64.P$24 (VM1_24); also elsewhere on the board

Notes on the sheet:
Motors

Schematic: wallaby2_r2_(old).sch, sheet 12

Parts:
C54: 0.1uF 20V; 0603-CAP
U67: AT24CS01-STUM-T; SOT-23-5

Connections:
GND: C54.2, U67.P$2 (2_GND), U67.P$5 (5_WP); also elsewhere on the board
PI_I2C1_SCL: U67.P$1 (1_SCL); also elsewhere on the board
PI_I2C1_SDA: U67.P$3 (3_SDA); also elsewhere on the board
VCC_3V3: C54.1, U67.P$4 (4_VCC); also elsewhere on the board

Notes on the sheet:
EEPROM Address 0x50

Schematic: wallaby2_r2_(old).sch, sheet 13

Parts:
C69, C70: 0.1uF; 0603
C71: 10pF; 0603
U5: 9DoF IMU; QFN24-3X3

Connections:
GND: C69.2, C70.2, C71.2, U5.11 (FSYNC), U5.18 (GND), U5.20 (GND); also elsewhere on the board
IMU_SPI_CLK: U5.23 (SCL/SCLK); also elsewhere on the board
IMU_SPI_CS0: U5.22 (!CS); also elsewhere on the board
IMU_SPI_MISO: U5.9 (AD0/SDO); also elsewhere on the board
IMU_SPI_MOSI: U5.24 (SDA/SDI); also elsewhere on the board
unnamed: C70.1, U5.10 (REGOUT)
VCC_3V3: C69.1, C71.1, U5.1 (VDDIO), U5.8 (VDDIO), U5.13 (VDD); also elsewhere on the board

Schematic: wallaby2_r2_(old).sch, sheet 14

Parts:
D4: red; LED-0603
Q1, Q2: BSP170P; SOT223
R10: 1K; 0603-RES
R37: 3K3; 0603-RES
R38: 100K; 0603-RES
U3: XT60; XT60-FP-MH
U35: SWITCH-OS102011MA1QN1; OS-SPDT-MINI-SLIDE_SWITCH
U74: 2920L500-16MR; FUSE-2920

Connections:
GND: R10.1, U3.NEG (CONN_N), U35.P$1; also elsewhere on the board
unnamed: D4.C, R10.2
unnamed: R37.2, U35.P$2
unnamed: Q1.1 (G), Q2.1 (G), R37.1, R38.2
VCC_3V3: D4.A; also elsewhere on the board
VCC_BATT_FUSE: U74.P$2; also elsewhere on the board
VCC_BATT_NO_FUSE: Q1.2 (D), Q1.4 (D); also elsewhere on the board
VCC_BATT_PRE_FUSE: Q2.2 (D), Q2.4 (D), U74.P$1
VCC_BATT_RAW: Q1.3 (S), Q2.3 (S), R38.1, U3.POS (CONN_P); also elsewhere on the board

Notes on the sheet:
Power

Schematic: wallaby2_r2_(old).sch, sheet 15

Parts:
C14: 10uF; 0603
C15: 0.1uF; 0603
C23, C72: 22pF; 0603
FB5, FB6: Ferrite; _0805MP
J4: CONN_02; 1X02
R61: 1M; 0603
R62, R63: DNP; 0603
U45: MAX98357; TQFN-16

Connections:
GND: C14.2, C15.2, C23.2, C72.2, R63.1, U45.GND, U45.P$3 (GND), U45.P$11 (GND), U45.P$15 (GND); also elsewhere on the board
I2S_BCLK: U45.P$16 (BCLK); also elsewhere on the board
I2S_DIN: U45.P$1 (DIN); also elsewhere on the board
I2S_LRCLK: U45.P$14 (LRCLK); also elsewhere on the board
unnamed: FB5.1, U45.P$9 (OUTP)
unnamed: FB6.1, U45.P$10 (OUTN)
unnamed: C23.1, FB5.2, J4.1
unnamed: C72.1, FB6.2, J4.2
unnamed: R61.1, U45.P$4 (SD)
unnamed: R62.1, R63.2, U45.P$2 (GAIN)
VCC_5V0: C14.1, C15.1, R61.2, R62.2, U45.P$7 (VDD), U45.P$8 (VDD); also elsewhere on the board

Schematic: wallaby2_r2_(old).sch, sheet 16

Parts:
C2, C3, C4, C5, C6, C7, C8, C9, C10, C11, C13, C19, C74: 0.1uF; 0603
C12, C73: 2.2uF; 0603
C16: 10uF; 0805-NO
C17, C18: 1uF; 0805-NO
D1: MBR0540; SOD-123
D2: MM3Z24VT1G; SMADIODE
D3: 1N4148; SOD-323
FB1, FB2, FB3, FB4: Ferrite; _0805MP
J9: 40PINFPCM4-1734839-0; 4-1734839-0
L1: 15uH; INDUCTOR_5X5MM_NR5040_NOTHERMALS
R1, R2, R3, R4, R5, R8: 10k; 0603
R6, R67, R72, R73: 0; 0603
R7: 47k; 0603
R15, R16: 12; 0805-NO
R70, R71: DNP; 0603
SJ1, SJ2: SOLDERJUMPER; SOLDERJUMPER_ARROW_NOPASTE
SJ3: -25mA; SOLDERJUMPER_CLOSEDWIRE
U1: TFP401; S-PQFP-G100
U2: 24LC02BT-I/OT; SOT23-5
U4: FAN5333BSX; SOT23-5
U31, U32, U33, U34: MOUNTINGHOLE3.0; MOUNTINGHOLE_3.0_PLATED
U$8: TSC2003; TSSOP16
X1: 47151-0001; HDMI_MOLEX_47151-0001_DIMLAYER

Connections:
5.0V: C13.1, R1.1, R3.2, R4.2, U2.4 (VCC), X1.18 (+5V)
24V: C17.1, C18.1, D1.C, D2.C, J9.2 (MS)
ACTIVE: D3.C, J9.31 (MS), U1.8 (SCDT)
AVDD: C9.1, C11.1, FB3.2, U1.82 (AVDD), U1.84 (AVDD), U1.88 (AVDD), U1.95 (AVDD)
B0: J9.21 (MS), U1.10 (QE0)
B1: J9.22 (MS), U1.11 (QE1)
B2: J9.23 (MS), U1.12 (QE2)
B3: J9.24 (MS), U1.13 (QE3)
B4: J9.25 (MS), U1.14 (QE4)
B5: J9.26 (MS), U1.15 (QE5)
B6: J9.27 (MS), U1.16 (QE6)
B7: J9.28 (MS), U1.17 (QE7)
CTL1: U1.40 (CTL1)
CTL2: U1.41 (CTL2)
CTL3: U1.42 (CTL3)
DISPEN: J9.34 (MS), U1.46 (DE)
G0: J9.13 (MS), U1.20 (QE8)
G1: J9.14 (MS), U1.21 (QE9)
G2: J9.15 (MS), U1.22 (QE10)
G3: J9.16 (MS), U1.23 (QE11)
G4: J9.17 (MS), U1.24 (QE12)
G5: J9.18 (MS), U1.25 (QE13)
G6: J9.19 (MS), U1.26 (QE14)
G7: J9.20 (MS), U1.27 (QE15)
GND: C2.2, C3.2, C4.2, C5.2, C6.2, C7.2, C8.2, C9.2, C10.2, C11.2, C12.2, C13.2, C16.1, C17.2, C18.2, C19.2, C73.2, C74.2, J9.3 (MS), J9.29 (MS), J9.36 (MS), R5.1, R15.2, R16.2, R72.2, R73.2, SJ2.1, U1.1 (DFO), U1.4 (PIXS), U1.5 (GND), U1.19 (OGND), U1.28 (OGND), U1.39 (GND), U1.45 (OGND), U1.58 (OGND), U1.68 (GND), U1.76 (OGND), U1.79 (AGND), U1.83 (AGND), U1.87 (AGND), U1.89 (AGND), U1.92 (AGND), U1.98 (PGND), U1.P$1 (TP), U1.P$2 (TP), U1.P$3 (TP), U1.P$4 (TP), U1.P$5 (TP), U1.P$6 (TP), U1.P$7 (TP), U1.P$8 (TP), U1.P$9 (TP), U1.P$10 (TP), U1.P$11 (TP), U1.P$12 (TP), U1.P$13 (TP), U1.P$14 (TP), U1.P$15 (TP), U1.P$16 (TP), U1.THERMAL (TP), U2.2 (GND), U2.5 (WP), U4.2 (GND), U$8.P$6 (6_GND), X1.2 (TX2_SHIELD), X1.5 (TX1_SHIELD), X1.8 (TX0_SHIELD), X1.11 (TXC_SHIELD), X1.17 (GND), X1.P$1 (GND), X1.P$2 (GND), X1.P$3 (GND), X1.P$4 (GND); also elsewhere on the board
HSYNC: J9.32 (MS), U1.48 (HSYNC)
LEDK: C19.1, D2.A, J9.1 (MSV), R16.1, SJ3.2, U4.3 (FB)
unnamed: U1.93 (RXC+), X1.10 (TXC+)
unnamed: U1.94 (RXC-), X1.12 (TXC-)
unnamed: U1.90 (RX0+), X1.7 (TX0+)
unnamed: U1.91 (RX0-), X1.9 (TX0-)
unnamed: U1.85 (RX1+), X1.4 (TX1+)
unnamed: U1.86 (RX1-), X1.6 (TX1-)
unnamed: U1.80 (RX2+), X1.1 (TX2+)
unnamed: U1.81 (RX2-), X1.3 (TX2-)
unnamed: R1.2, X1.19 (HOTPLUG)
unnamed: R67.1, U$8.P$7 (7_VBAT1)
unnamed: C73.1, C74.1, R6.2, U$8.P$9 (9_VREF)
unnamed: R71.2, R73.1, U$8.P$13 (13_A1)
unnamed: D1.A, L1.P$2 (2), U4.1 (SW)
unnamed: R15.1, SJ3.1
unnamed: D3.A, R8.1, U4.4 (SHDN)
unnamed: R70.2, R72.1, U$8.P$14 (14_A0)
OCK_INV: R5.2, SJ1.1, U1.100 (OCK_INV)
OVDD: C5.1, C6.1, C7.1, C8.1, FB2.2, U1.18 (OVDD), U1.29 (OVDD), U1.43 (OVDD), U1.57 (OVDD), U1.78 (OVDD)
PIXCLK: J9.30 (MS), U1.44 (ODCK)
PI_GPIO25: R7.2, U$8.P$10 (10_PEN); also elsewhere on the board
PI_I2C1_SCL: U$8.P$12 (12_SCL); also elsewhere on the board
PI_I2C1_SDA: U$8.P$11 (11_SDA); also elsewhere on the board
PVDD: C10.1, FB4.2, U1.97 (PVDD)
PWRDN: U1.2 (#PD)
PWRDN_O: U1.9 (#PDO)
R0: J9.5 (MS), U1.30 (QE16)
R1: J9.6 (MS), U1.31 (QE17)
R2: J9.7 (MS), U1.32 (QE18)
R3: J9.8 (MS), U1.33 (QE19)
R4: J9.9 (MS), U1.34 (QE20)
R5: J9.10 (MS), U1.35 (QE21)
R6: J9.11 (MS), U1.36 (QE22)
R7: J9.12 (MS), U1.37 (QE23)
SCL: R4.1, U2.1 (SCL), X1.15 (DCLK)
SDA: R3.1, U2.3 (SDA), X1.16 (DDAT)
ST: R2.1, SJ2.2, U1.3 (ST)
VCC_3V3: C4.1, C12.1, FB1.1, FB2.1, FB3.1, FB4.1, J9.4 (MS), R6.1, R7.1, R67.2, R70.1, R71.1, U$8.P$1 (1_VDD); also elsewhere on the board
VCC_5V0: C16.2, L1.P$1 (1), R8.2, U4.5 (VIN); also elsewhere on the board
VDDIO: C2.1, C3.1, FB1.2, R2.2, SJ1.2, U1.6 (DVDD), U1.7 (#STAG), U1.38 (DVDD), U1.67 (DVDD), U1.99 (RSVD)
VSYNC: J9.33 (MS), U1.47 (VSYNC)
X+: J9.37 (MS), U$8.P$2 (2_XP)
X-: J9.39 (MS), U$8.P$4 (4_XN)
Y+: J9.38 (MS), U$8.P$3 (3_YP)
Y-: J9.40 (MS), U$8.P$5 (5_XP)

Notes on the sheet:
DNP

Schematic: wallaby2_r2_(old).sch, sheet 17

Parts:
FID1, FID2, FID3, FID4, FID5, FID6: FIDUCIAL1X2.5; FIDUCIAL-1X2.5

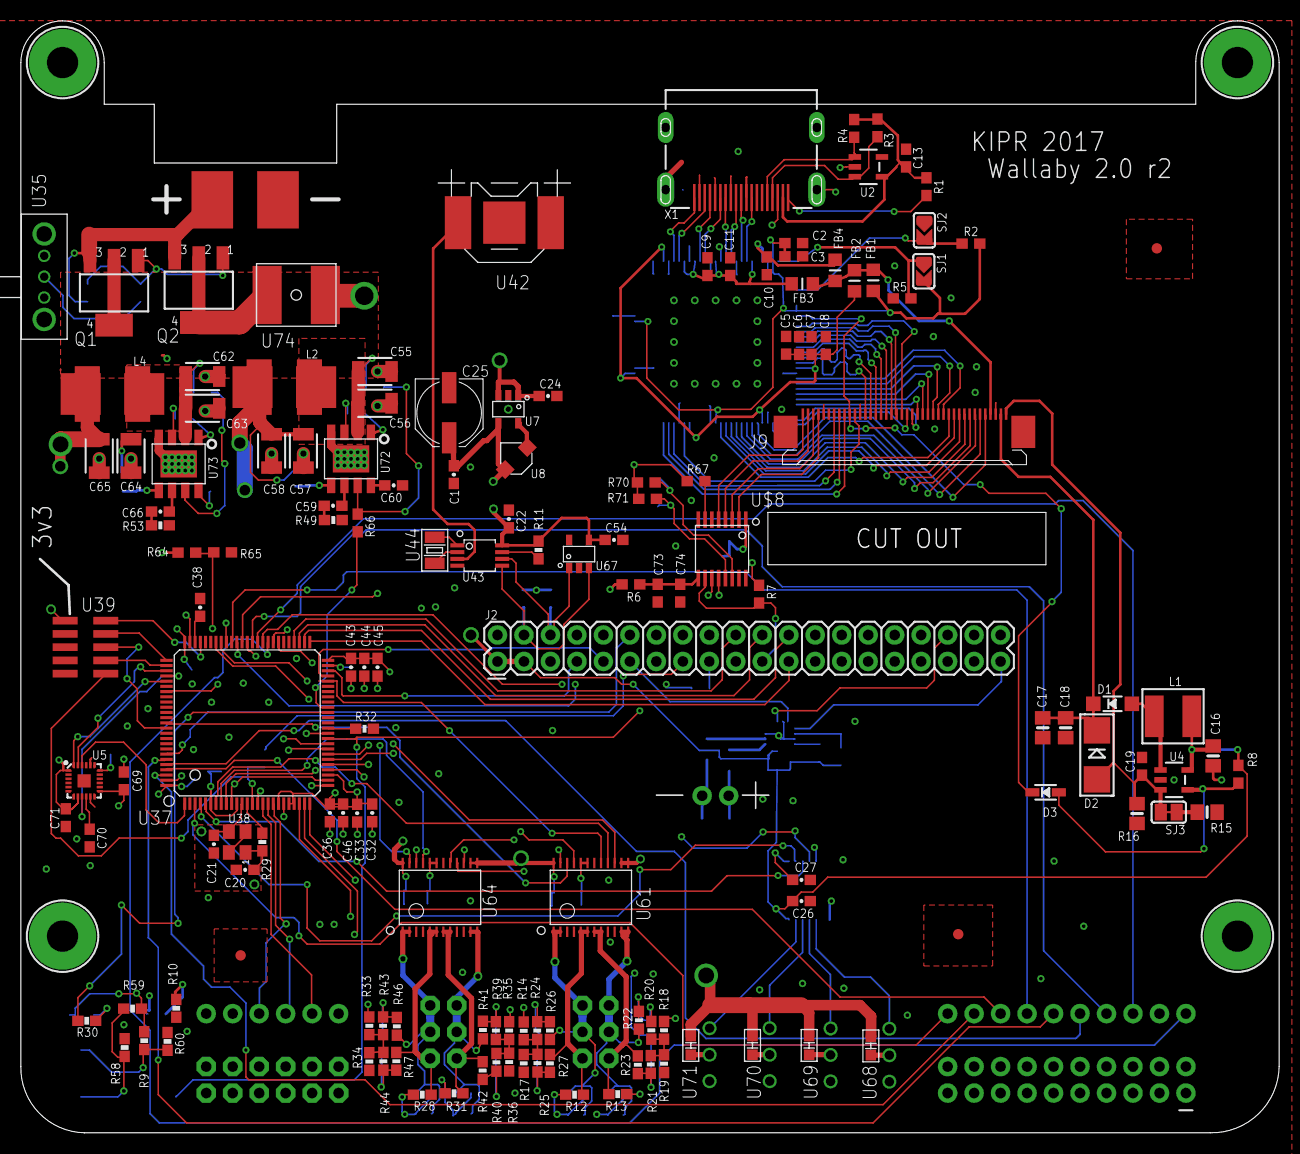
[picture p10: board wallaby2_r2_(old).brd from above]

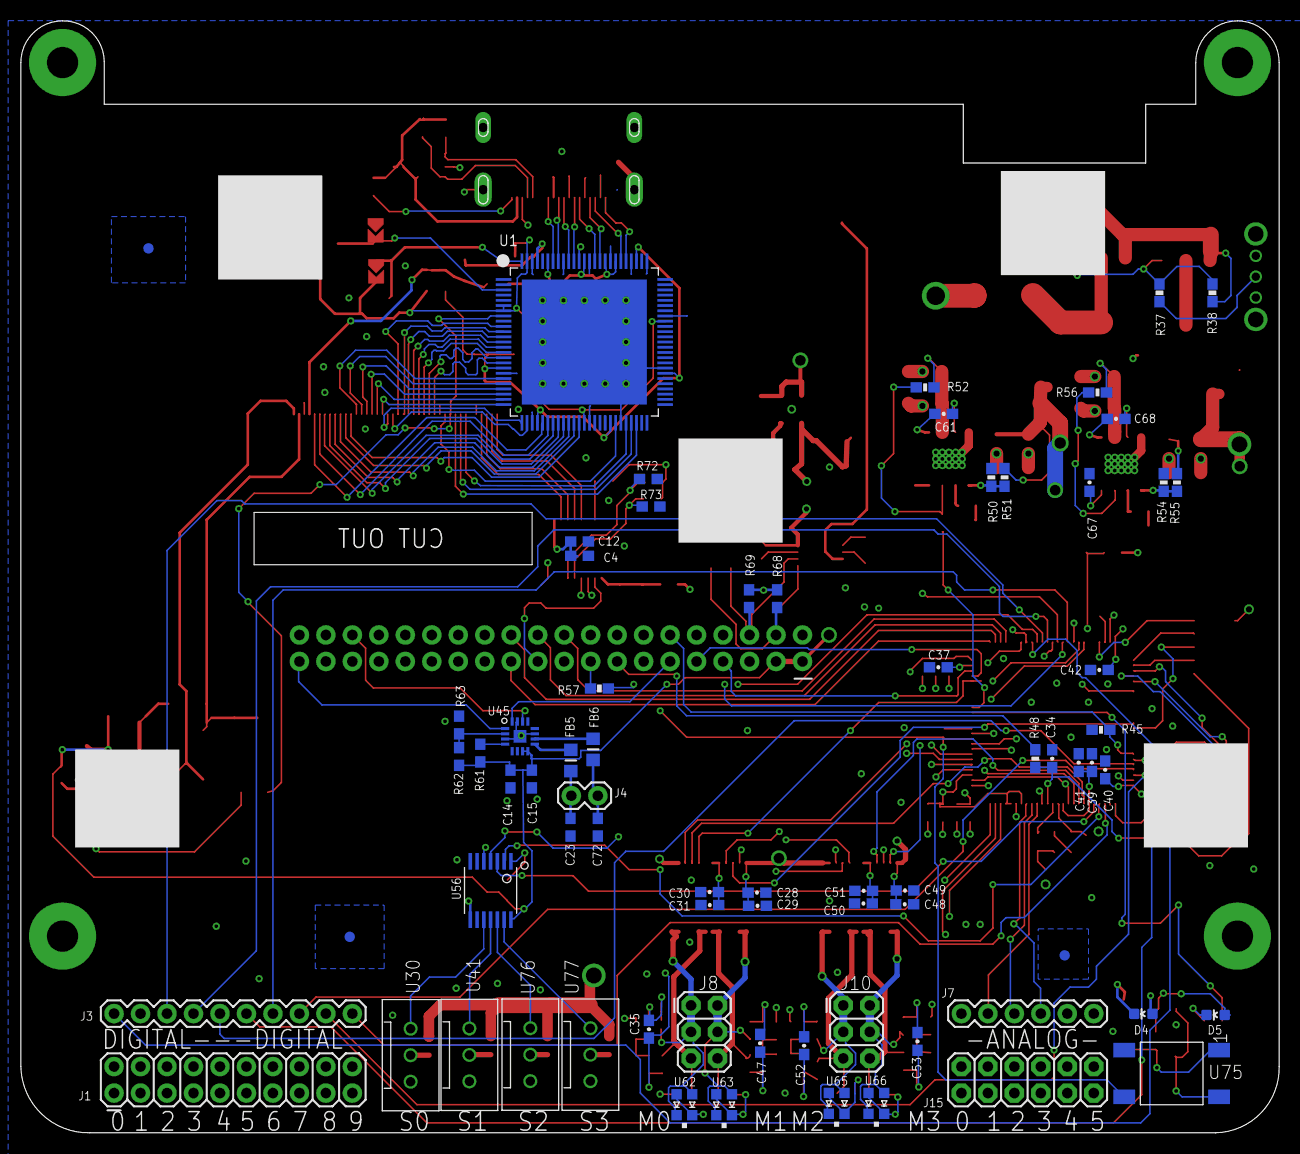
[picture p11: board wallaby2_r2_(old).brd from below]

Board: 6 copper layers, 120.7 x 106.7 mm, 222 parts (71 on the bottom side), 198 nets.

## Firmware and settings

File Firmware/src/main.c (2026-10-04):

// Author: Joshua Southerland (2015)

// #define USE_CROSS_STUDIO_DEBUG

// STM32F405RG (see stm32f4xx.h to change target device)
// you have to uncomment one of the options, I chose:
//#define STM32F427_437xx

// assert_param undefined reference errors are solved by defining USE_STDPERIPH_DRIVER
//#define USE_STDPERIPH_DRIVER

// for startup file, make sure  STARTUP_FROM_RESET is defined

// also have to specify the external crystal speed
//#define HSE_VALUE=16000000

#include "stm32f4xx.h"

#include "wallaby.h"

 

int main()
{
    int32_t bemf_vals[4] = {0,0,0,0};
    int32_t bemf_vals_filt[4] = {0,0,0,0};

    init();

    // set up DMA/SPI buffers
    init_rx_buffer();
    init_tx_buffer();

    // set up pid structs
    pid_struct pid_structs[4];

    {        uint8_t i;
        for (i = 0; i < 4; ++i) init_pid_struct(&(pid_structs[i]), i);
    }

    update_dig_pin_configs();
    config_adc_in_from_regs();

    //debug_printf("starting\n");
    int low_volt_alarmed = 0;

    // Loop until button is pressed
    uint32_t count = 0;
    while (1)
    {
        count += 1;
        {
            // only sample motor backemf 1/4 of the time
            const uint8_t bemf_update_time =  (count % 4 == 1);
            if (bemf_update_time)
            {
                // idle breaking
                MOT0_DIR1_PORT->BSRRH |= MOT0_DIR1; 
                MOT0_DIR2_PORT->BSRRH |= MOT0_DIR2;
                MOT1_DIR1_PORT->BSRRH |= MOT1_DIR1; 
                MOT1_DIR2_PORT->BSRRH |= MOT1_DIR2;
                MOT2_DIR1_PORT->BSRRH |= MOT2_DIR1; 
                MOT2_DIR2_PORT->BSRRH |= MOT2_DIR2;
                MOT3_DIR1_PORT->BSRRH |= MOT3_DIR1; 
                MOT3_DIR2_PORT->BSRRH |= MOT3_DIR2;
            }
            // let the motor coast
            // delay_us(700);
            // now I squeeze in most sensor updates instead of just sleeping
            uint32_t before = usCount;
            update_dig_pins();
            int16_t batt = adc_update();
            // readIMU decides internally which sensors are due this pass
            readIMU(count);

            if (batt < 636) // about 5.75 volts
            {
                configDigitalOutPin(LED1_PIN, LED1_PORT);
                low_volt_alarmed = 1;
                if (count % 50 < 10) // low duty cycle to save battery
                {
                    LED1_PORT->BSRRL |= LED1_PIN; // ON
                }
                else
                {
                    LED1_PORT->BSRRH |= LED1_PIN; // OFF
                }
            }
            else if (low_volt_alarmed)
            {
                // make sure led is off coming out of the low voltage alarm
                configDigitalOutPin(LED1_PIN, LED1_PORT);
                LED1_PORT->BSRRH |= LED1_PIN; // OFF
                low_volt_alarmed = 0;
            }

            if (adc_dirty)
            {
                adc_dirty = 0;
                config_adc_in_from_regs();
            }

            if (dig_dirty)
            {
                dig_dirty = 0;
                update_dig_pin_configs();
            }

            uint32_t sensor_update_time = usCount - before;
            const uint16_t us_delay_needed = 700;
            const uint8_t got_time_to_burn = sensor_update_time < us_delay_needed;

            if (got_time_to_burn)
            {
                // sleep the remainder of the coasting period before sampling bemf
                delay_us(us_delay_needed-sensor_update_time);
            }

            if (bemf_update_time)
            {
                update_bemfs(bemf_vals, bemf_vals_filt);

                // set the motor directions back up
                update_motor_modes();

                uint8_t channel;
                for (channel = 0; channel < 4; ++channel)
                {
                    uint8_t shift = 2*channel;
                    uint8_t motor_mode = (aTxBuffer[REG_RW_MOT_MODES] & (0b11 << shift)) >> shift;
                    motor_update(bemf_vals[channel], bemf_vals_filt[channel], &pid_structs[channel], channel, motor_mode);
                }

            }
            else
            {
                // updating sensors doesnt' take as long as all of the adc for backemf updates
                // sleep a bit so that our time through the loop is consistent for PID control
                delay_us(222);
            }

            //aTxBuffer[REG_RW_MOT_SRV_ALLSTOP] = 0;//FIXME: remove
        }
    } 

    // set all motor pwms to 0
    aTxBuffer[REG_RW_MOT_0_PWM_H] = 0;
    aTxBuffer[REG_RW_MOT_0_PWM_L] = 0;
    aTxBuffer[REG_RW_MOT_1_PWM_H] = 0;
    aTxBuffer[REG_RW_MOT_1_PWM_L] = 0;
    aTxBuffer[REG_RW_MOT_2_PWM_H] = 0;
    aTxBuffer[REG_RW_MOT_2_PWM_L] = 0;
    aTxBuffer[REG_RW_MOT_3_PWM_H] = 0;
    aTxBuffer[REG_RW_MOT_3_PWM_L] = 0;

    // set all motors to idle state
    idle_motor_dirs();

    spi2_dma_cleanup();

    //debug_printf("done\n");
}

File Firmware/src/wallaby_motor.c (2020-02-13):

#include "wallaby_motor.h"

#include "wallaby.h"

#include "string.h" // memset


void configMotorPin(uint32_t pin, GPIO_TypeDef* port)
{
    GPIO_InitTypeDef GPIO_InitStructure;
    GPIO_InitStructure.GPIO_Pin = pin;
    GPIO_InitStructure.GPIO_Mode = GPIO_Mode_OUT;
    GPIO_InitStructure.GPIO_OType = GPIO_OType_PP;
    GPIO_InitStructure.GPIO_Speed = GPIO_Speed_2MHz;
    GPIO_InitStructure.GPIO_PuPd = GPIO_PuPd_NOPULL;
    GPIO_Init(port, &GPIO_InitStructure);
}



void update_motor_mode(uint32_t dir1_pin, uint32_t dir2_pin, GPIO_TypeDef* dir1_port, GPIO_TypeDef* dir2_port, uint8_t drive_code)
{

    switch(drive_code)
    {
        case 0:
            dir1_port->BSRRH |= dir1_pin; 
            dir2_port->BSRRH |= dir2_pin;
            break;
        case 1:
            dir1_port->BSRRL |= dir1_pin; 
            dir2_port->BSRRH |= dir2_pin;
            break;
        case 2:
            dir1_port->BSRRH |= dir1_pin; 
            dir2_port->BSRRL |= dir2_pin;
            break;
        case 3:
            dir1_port->BSRRL |= dir1_pin; 
            dir2_port->BSRRL |= dir2_pin;
            break;
        default:
            break;
    }
}

void update_motor_modes()
{
    uint8_t motor_0_mode = (aTxBuffer[REG_RW_MOT_DIRS] & 0b00000011);
    uint8_t motor_1_mode = (aTxBuffer[REG_RW_MOT_DIRS] & 0b00001100) >> 2;
    uint8_t motor_2_mode = (aTxBuffer[REG_RW_MOT_DIRS] & 0b00110000) >> 4;
    uint8_t motor_3_mode = (aTxBuffer[REG_RW_MOT_DIRS] & 0b11000000) >> 6;

    update_motor_mode(MOT0_DIR1, MOT0_DIR2, MOT0_DIR1_PORT, MOT0_DIR2_PORT, motor_0_mode);
    update_motor_mode(MOT1_DIR1, MOT1_DIR2, MOT1_DIR1_PORT, MOT1_DIR2_PORT, motor_1_mode);
    update_motor_mode(MOT2_DIR1, MOT2_DIR2, MOT2_DIR1_PORT, MOT2_DIR2_PORT, motor_2_mode);
    update_motor_mode(MOT3_DIR1, MOT3_DIR2, MOT3_DIR1_PORT, MOT3_DIR2_PORT, motor_3_mode);
}

void idle_motor_dirs()
{
    aTxBuffer[REG_RW_MOT_MODES] = 0;
}



void motor_update(int16_t bemf_val, int16_t bemf_val_filt, pid_struct * pids, uint8_t channel, uint8_t motor_mode)
{
    static const uint8_t MOT_SP_REG_STRIDE = 2;
    static const uint8_t MOT_PWM_REG_STRIDE = 2;
    static const uint8_t MOT_POS_REG_STRIDE = 4; // 32 bit position
    static const uint8_t MOT_POS_GOAL_REG_STRIDE = 4;
    
    if ((bemf_val < 8) && (bemf_val > -8)) bemf_val = 0;

    const uint16_t mot_pos_address = REG_RW_MOT_0_B3 + MOT_POS_REG_STRIDE * channel;
    int32_t pos = ((int32_t)aTxBuffer[mot_pos_address] << 24) | ((int32_t)aTxBuffer[mot_pos_address+1] << 16) | ((int32_t)aTxBuffer[mot_pos_address+2] << 8) | ((int32_t)aTxBuffer[mot_pos_address+3]);
    pos += bemf_val_filt;
    aTxBuffer[mot_pos_address]   = (pos & 0xFF000000) >> 24;
    aTxBuffer[mot_pos_address+1] = (pos & 0x00FF0000) >> 16;
    aTxBuffer[mot_pos_address+2] = (pos & 0x0000FF00) >> 8;
    aTxBuffer[mot_pos_address+3] = (pos & 0x000000FF);

        // TODO: more concise way of this?
        // something like   ~(0b11 << (6- 2*channel))
        uint8_t dir_mask = 0xff;
        switch(channel)
        {
            case 0:
                dir_mask = 0b11111100;
                break;
            case 1:
                dir_mask = 0b11110011;
                break;
            case 2:
                dir_mask = 0b11001111;
                break;
            case 3:
                dir_mask = 0b00111111;
                break;
            default:
                break;
        }


    uint8_t motor_done = aTxBuffer[REG_RW_MOT_DONE] & (1 << channel);
    uint8_t motor_stop = aTxBuffer[REG_RW_MOT_SRV_ALLSTOP] & (1 << channel);

    // TODO: maybe move this logic so it integrates with code below better
    if (motor_stop)
    {
        uint16_t ucmd = 0;

        // passive braking
        aTxBuffer[REG_RW_MOT_DIRS] = (aTxBuffer[REG_RW_MOT_DIRS] & dir_mask) | (0b00 << (2*channel));

        // TODO multi channel is a little messy here
        aTxBuffer[REG_RW_MOT_0_PWM_H + MOT_PWM_REG_STRIDE * channel] = (ucmd & 0xFF00) >> 8;
        aTxBuffer[REG_RW_MOT_0_PWM_L + MOT_PWM_REG_STRIDE * channel] = (ucmd & 0x00FF);

        update_motor_modes();
        return;
    }

    if (motor_mode == 0)
    {
        // PWM mode
    }
    else if (motor_done ==0)
    {
        // PID Control Needed   (MAV, MTP, MRP)
        const uint16_t goal_address = REG_RW_MOT_0_SP_H + MOT_SP_REG_STRIDE * channel;
        int32_t goal = (((int16_t)(aTxBuffer[goal_address])) << 8) | ((int16_t)(aTxBuffer[goal_address+1]));
        if (aTxBuffer[goal_address] & 0b10000000) goal |= 0xFFFF0000;// TODO: cleanup negative goal handling
        const int32_t current = (int32_t)bemf_val;
    
        const float pErr =  (float)(goal-current); //(float)(goal - current);
        const float dErr = pErr - pids->prevErr;

        pids->prevErr = pErr;
        pids->iErr += pErr;

        // clamp error integral
        static const float max_iErr = 10000.0f; 
        if (pids->iErr > max_iErr)
        {
            pids->iErr = max_iErr;
        }
        else if (pids->iErr < -max_iErr)
        {
            pids->iErr = -max_iErr;
        }

        int32_t cmd = (int32_t)(pids->kP*pErr + pids->kI*pids->iErr + pids->kD*dErr);

        // Move To Position or  Move Relative Position goal checks
        if (motor_mode == MOT_MODE_MTP || motor_mode == MOT_MODE_MRP)
        {
            const uint16_t mot_pos_goal_address = REG_W_MOT_0_GOAL_B3 + MOT_POS_GOAL_REG_STRIDE * channel;
            int32_t pos_goal = ((int32_t)aTxBuffer[mot_pos_goal_address] << 24) | ((int32_t)aTxBuffer[mot_pos_goal_address+1] << 16) | ((int32_t)aTxBuffer[mot_pos_goal_address+2] << 8) | ((int32_t)aTxBuffer[mot_pos_goal_address+3]);

            if (goal < 0)
            {
                if(pos < pos_goal){
                    cmd = 0;
                    aTxBuffer[REG_RW_MOT_DONE] |= (1 << channel);
                }
            }
            else
            {
                if(pos > pos_goal){
                    cmd = 0;
                    aTxBuffer[REG_RW_MOT_DONE] |= (1 << channel);
                }
            }
        }

        // clamp output signal
        static const uint16_t max_cmd = 400;
        if (cmd > max_cmd) cmd = max_cmd;
        if (cmd < -max_cmd) cmd = -max_cmd;

        // handle direction
        if (cmd < 0)
        {
            cmd = -cmd;
            //motor_mode[0] = 2; // reverse
            aTxBuffer[REG_RW_MOT_DIRS] =  (aTxBuffer[REG_RW_MOT_DIRS] & dir_mask) | (0b10 << (2*channel));
        }
        else
        {
            //motor_mode[0] = 1; //forward
            aTxBuffer[REG_RW_MOT_DIRS] = (aTxBuffer[REG_RW_MOT_DIRS] & dir_mask) | (0b01 << (2*channel));
        }

        // TODO: adjust for a physical deadband?

        // TODO: adjust or nonlinearity?

        // TODO: add simulated deadband?




        // set command
        uint16_t ucmd = (uint16_t)cmd;
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

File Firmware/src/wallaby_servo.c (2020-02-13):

#include "wallaby_servo.h"
#include "wallaby.h"

#include "stm32f4xx.h"


void configServoPin(uint32_t pin, GPIO_TypeDef* port)
{
    GPIO_InitTypeDef GPIO_InitStructure;
    GPIO_InitStructure.GPIO_Pin = pin;
    GPIO_InitStructure.GPIO_Mode = GPIO_Mode_OUT;
    GPIO_InitStructure.GPIO_OType = GPIO_OType_PP;
    GPIO_InitStructure.GPIO_Speed = GPIO_Speed_100MHz;
    GPIO_InitStructure.GPIO_PuPd = GPIO_PuPd_NOPULL;
    GPIO_Init(port, &GPIO_InitStructure);
}

void TIM3_Configuration(void)
{
  TIM_OCInitTypeDef  TIM_OCInitStructure;
  TIM_TimeBaseInitTypeDef  TIM_TimeBaseStructure;
 
  /* Time base configuration - SystemCoreClock = 168000000 for 168 MHz board */
  TIM_TimeBaseStructure.TIM_Prescaler = (uint16_t) (((SystemCoreClock / 1000000) / 2) - 1); // Shooting for 1 MHz, (1us)
  TIM_TimeBaseStructure.TIM_Period = 20000 - 1; // 1 MHz / 20000 = 50 Hz (20ms)
  TIM_TimeBaseStructure.TIM_ClockDivision = 0;
  TIM_TimeBaseStructure.TIM_CounterMode = TIM_CounterMode_Up;
  TIM_TimeBaseInit(TIM3, &TIM_TimeBaseStructure);
 
  /* Enable TIM4 Preload register on ARR */
  TIM_ARRPreloadConfig(TIM3, ENABLE);
 
  /* TIM PWM1 Mode configuration: Channel */
  TIM_OCInitStructure.TIM_OCMode = TIM_OCMode_PWM1;
  TIM_OCInitStructure.TIM_OutputState = TIM_OutputState_Enable;
  TIM_OCInitStructure.TIM_Pulse = 1500; // Servo Top-Center
  TIM_OCInitStructure.TIM_OCPolarity = TIM_OCPolarity_High;
 
  /* Output Compare PWM1 Mode configuration: Channel2 PD.13 */
  TIM_OC2Init(TIM3, &TIM_OCInitStructure);
  TIM_OC2PreloadConfig(TIM3, TIM_OCPreload_Enable);
 
  /* Output Compare PWM1 Mode configuration: Channel3 PD.14 */
  TIM_OC3Init(TIM3, &TIM_OCInitStructure);
  TIM_OC3PreloadConfig(TIM3, TIM_OCPreload_Enable);
 
  /* TIM Interrupts enable */
  TIM_ITConfig(TIM3, TIM_IT_Update, ENABLE);
 
  /* TIM4 enable counter */
  TIM_Cmd(TIM3, ENABLE);
}


void TIM9_Configuration(void)
{
  TIM_OCInitTypeDef  TIM_OCInitStructure;
  TIM_TimeBaseInitTypeDef  TIM_TimeBaseStructure;
 
  /* Time base configuration - SystemCoreClock = 168000000 for 168 MHz board */
  TIM_TimeBaseStructure.TIM_Prescaler = (uint16_t) (((SystemCoreClock / 1000000)) - 1); // Shooting for 1 MHz, (1us)
  TIM_TimeBaseStructure.TIM_Period = 20000 - 1; // 1 MHz / 20000 = 50 Hz (20ms)
  TIM_TimeBaseStructure.TIM_ClockDivision = 0;
  TIM_TimeBaseStructure.TIM_CounterMode = TIM_CounterMode_Up;
  TIM_TimeBaseInit(TIM9, &TIM_TimeBaseStructure);
 
  /* Enable TIM4 Preload register on ARR */
  TIM_ARRPreloadConfig(TIM9, ENABLE);
 
  /* TIM PWM1 Mode configuration: Channel */
  TIM_OCInitStructure.TIM_OCMode = TIM_OCMode_PWM1;
  TIM_OCInitStructure.TIM_OutputState = TIM_OutputState_Enable;
  TIM_OCInitStructure.TIM_Pulse = 1500; // Servo Top-Center
  TIM_OCInitStructure.TIM_OCPolarity = TIM_OCPolarity_High;
 
  /* Output Compare PWM1 Mode configuration: Channel1 PD.12 */
  TIM_OC1Init(TIM9, &TIM_OCInitStructure);
  TIM_OC1PreloadConfig(TIM9, TIM_OCPreload_Enable);
 
  /* Output Compare PWM1 Mode configuration: Channel2 PD.13 */
  TIM_OC2Init(TIM9, &TIM_OCInitStructure);
  TIM_OC2PreloadConfig(TIM9, TIM_OCPreload_Enable);

  /* TIM Interrupts enable */
  TIM_ITConfig(TIM9, TIM_IT_Update, ENABLE);
 
  /* TIM4 enable counter */
  TIM_Cmd(TIM9, ENABLE);
}

void TIM3_IRQHandler(void)
{
    if (TIM_GetITStatus(TIM3, TIM_IT_Update) != RESET)
    {
        TIM_ClearITPendingBit(TIM3, TIM_IT_Update);

        uint32_t servo0_cmd = (((uint32_t)aTxBuffer[REG_RW_SERVO_0_H]) << 8) | ((uint32_t)aTxBuffer[REG_RW_SERVO_0_L]);
        uint32_t servo1_cmd = (((uint32_t)aTxBuffer[REG_RW_SERVO_1_H]) << 8) | ((uint32_t)aTxBuffer[REG_RW_SERVO_1_L]);

        if (aTxBuffer[REG_RW_MOT_SRV_ALLSTOP] & 0b00010000) servo0_cmd = 0;
        if (aTxBuffer[REG_RW_MOT_SRV_ALLSTOP] & 0b00100000) servo1_cmd = 0;

        TIM_SetCompare2(TIM3, servo1_cmd);
        TIM_SetCompare3(TIM3, servo0_cmd);
    }
}


void TIM1_BRK_TIM9_IRQHandler(void)
{
    if (TIM_GetITStatus(TIM9, TIM_IT_Update) != RESET)
    {
        TIM_ClearITPendingBit(TIM9, TIM_IT_Update);

        uint32_t servo2_cmd = (((uint32_t)aTxBuffer[REG_RW_SERVO_2_H]) << 8) | ((uint32_t)aTxBuffer[REG_RW_SERVO_2_L]);
        uint32_t servo3_cmd = (((uint32_t)aTxBuffer[REG_RW_SERVO_3_H]) << 8) | ((uint32_t)aTxBuffer[REG_RW_SERVO_3_L]);

        if (aTxBuffer[REG_RW_MOT_SRV_ALLSTOP] & 0b01000000)
        {
            servo2_cmd = 0;
        }
        if (aTxBuffer[REG_RW_MOT_SRV_ALLSTOP] & 0b10000000) servo3_cmd = 0;

        TIM_SetCompare1(TIM9, servo3_cmd);
        TIM_SetCompare2(TIM9, servo2_cmd);
    }
}

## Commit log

2020-02-13 Moving Everything over to the seperate repository
    This was previously in another repo. Moving it into it's own.
    [Botball_v7.brd, Botball_v7.sch, Botball_v7_BOM.csv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]
2020-02-13 Updated the documents file
    [Wombat Lab Schematic.brd, Wombat Lab Schematic.sch, Wombat_BOM_rev4.xlsx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]
2021-04-20 Added IMU Setup
2026-09-26 Add agent scaffolding, contribution guidelines, and CI build
    Adds shared guidance so humans and AI coding agents can work on the
    firmware with a reliable build-and-verify loop:
    - AGENTS.md: architecture, build, verification, and gotchas. CLAUDE.md
    and GEMINI.md import it so every tool reads the same instructions.
    - CONTRIBUTING.md: owner-named branches, plan review before coding,
    focused non-speculative changes, comment and documentation norms.
    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
2026-10-01 Bounds-check host register writes in handle_dma
    handle_dma() trusted the packet's count byte and every write address.
    libwallaby zero-pads its packets, so any count larger than the real
    number of writes applied (0, 0) pairs and cleared the 'J' start byte,
    after which libwallaby logs "DMA de-synchronized" on every transfer until
    the STM32 resets. Larger counts read past the 89 bytes the DMA fills and
    then into aTxBuffer itself, and addresses of 153 or more wrote past the
    end of aTxBuffer.
    Packets whose count exceeds the 42 pairs that fit before the trailing
    'S' are now ignored, and writes to the start and version registers or
    past REG_ALL_COUNT are skipped. libwallaby sends 1-4 writes to add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
    [wallaby_dma.c]
2026-10-01 Clamp oversized write counts instead of dropping the packet
    Dropping every write from a packet whose count byte exceeds 42 lost the
    real write whenever a count-byte bit flip pushed it above 42. That
    includes a flip of the top bit, which master happened to handle
    correctly because the count wrapped back to its real value. libwallaby
    zero-pads its packets and the address check already skips (0, 0) pairs,
    so clamping the count to 42 applies the real writes and nothing else.
    Also corrects the address-check comment: libwallaby checks only the
    start byte on every transfer, and nothing on the host reads the version
    registers. They're protected because the register map makes them
    read-only.
    Part o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
    [wallaby_dma.c]
2026-10-01 Resync the SPI link after a framing slip
    SPI2 runs as a slave feeding circular DMA of a fixed 89 bytes, and
    nothing realigned the DMA with the host's frames. One transfer of the
    wrong length, or a glitch on SCK or chip select, offset every later
    frame: the firmware dropped every host write and libwallaby logged "DMA
    de-synchronized" on every transfer until the STM32 was reset. botui#60
    reports this is common in the field, where reflashing (which resets the
    STM32) is the current fix.
    handle_dma() now sets spi_resync when a frame's start or end byte is
    wrong. A wrong version byte alone doesn't, since a reset can't fix a
    protocol mismatch. The main loop then calls spi2_dma_resync(), which
    wait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
    [main.c, wallaby_dma.c, wallaby_init.c]
2026-10-01 Detect slips from the RX count and wait out transfers
    Review of the first version found that recovery was slower than
    documented. The resync was only attempted once per 922 us main-loop
    pass and skipped whenever chip select was low, which is about 30% of the
    time under continuous traffic. A simulation with libwallaby's timing (89
    bytes at 16 MHz, usleep(50) between transfers) lost 5.7 transfers per
    slip on average, 16 at p95 and up to 54. The main loop now calls
    spi2_dma_check_sync() every pass, which:
    - Treats the link as slipped if, between transfers, the RX stream's
    count isn't a full frame. A wrong-length transfer shows up right
    after it ends, instead of one misaligned frame later.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
    [main.c, wallaby_dma.c]
2026-10-01 Drop unpadded corrupt packets and count rejected packets
    Clamping an oversized count to 42 applied 42 pairs even when the body
    was garbage too. On master a count of 128-169 wrapped and applied fewer.
    The real count is now recovered from where libwallaby's zero padding
    starts, and a packet with no padding is dropped. Single-bit flips of the
    count byte still apply exactly the real writes.
    Packets with a corrupt count or a skipped write used to be silent. They
    are now counted, mod 16, in the unused high nibble of REG_RW_MOT_DONE.
    The nibble is republished on every packet, so the main loop's
    read-modify-write of the done bits can't hold back a stale value. libkipr
    masks the done bits, so existi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
2026-10-04 IMU: non-blocking MPU9250 reads on top of PR #6 (#8)
    * IMU: non-blocking MPU9250 reads on top of PR #6
    Builds on @chrehall68's kipr/Wombat-Firmware#6, which rewrites the MPU9250
    driver against a proper register map and replaces the hand-rolled
    IMU_write(0x25, ...) sequences with named helpers.
    Changes on top of #6:
    - Remove ~1.98 ms of blocking delay from readIMU(). ACCEL_*OUT and GYRO_*OUT
    are latched by the MPU9250 at the configured sample rate, so no settling
    delay is needed between the two reads. main() only has a ~700 us coasting
    window before it must sample motor back-EMF, so blocking there stretched
    the loop and jittered PID timing.
    - Keep master's formatting in main.c rath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
    [main.c, wallaby_imu.c]
2026-10-12 Handle SPI frames on the RX stream's completion alone
    A transfer one byte short of a frame (88, 177, ... bytes) hung the
    firmware. The TX stream runs ahead of RX because the next reply byte is
    preloaded, so after such a transfer TX had completed a frame and RX had
    not. handle_dma() only cleared the transfer-complete flags when both
    were set, so the TX stream's interrupt re-entered until the host's next
    transfer. The main loop, SysTick and the motor and servo timer
    interrupts all stopped while the host was idle, and the main loop only
    ran while chip select was low, so spi2_dma_check_sync() never saw chip
    select high and could not resync.
    The same lone TX flag is set for about two byte times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
2026-10-13 Make disable_servos() go limp by cutting servo power
    disable_servo() only stops a port's control pulses; the 6 V servo rail
    stays on. Analog servos go limp without pulses, but digital servos,
    including the ones we use, keep holding their last position, so
    disable_servos() had no visible effect on them.
    PE10 drives the enable of U72, the one regulator for all four servo
    ports, but the firmware never configured it, so R52 kept the rail on.
    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
2026-10-13 Set PE10 before the clock switch and delay the servo power cut
    PE10 is now driven low at the top of init(), before init180MHz() waits
    for the crystal. The servo rail is on from reset until then, so this
    shortens the on/off blip after every reset.
    Servo power is now cut 40 ms after all four servos are disabled. The
    timer ISRs zero a port's pulse at its next 20 ms update, and compare
    preload applies that one period later, so cutting power within 1 ms
    drove up to one more pulse into an unpowered servo.
    AGENTS.md now lists the servo power check in the main loop's window.

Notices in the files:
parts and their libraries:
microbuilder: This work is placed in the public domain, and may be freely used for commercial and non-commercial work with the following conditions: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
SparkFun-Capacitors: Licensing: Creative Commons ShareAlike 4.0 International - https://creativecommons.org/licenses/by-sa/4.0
